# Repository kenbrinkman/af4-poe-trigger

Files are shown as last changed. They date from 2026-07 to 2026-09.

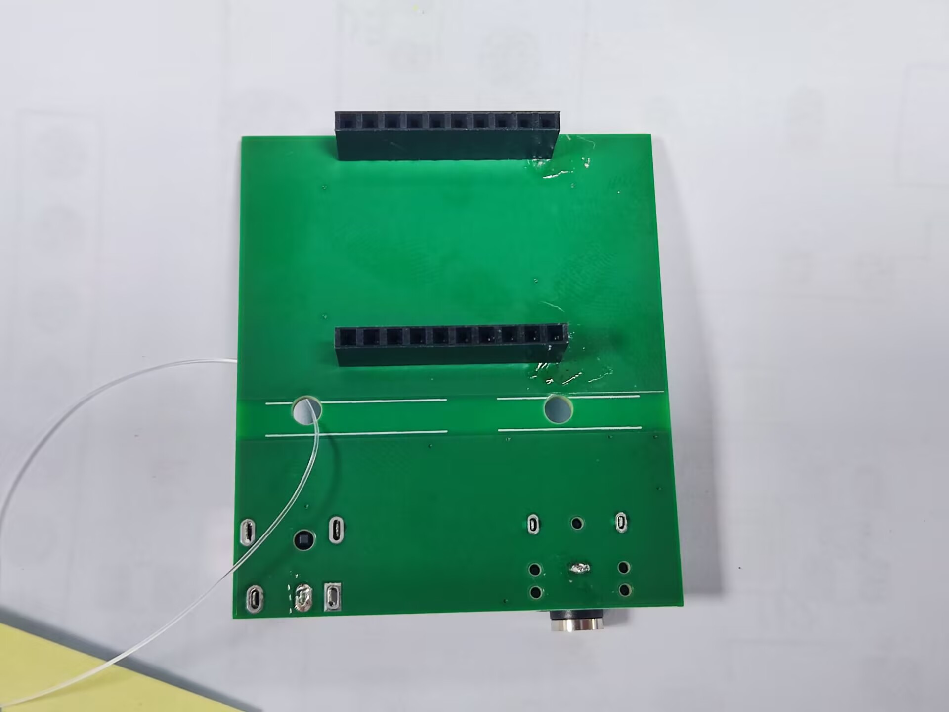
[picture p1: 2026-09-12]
pcb/BOARD REVIEW EQ/rework-2026-09-12-back.jpg

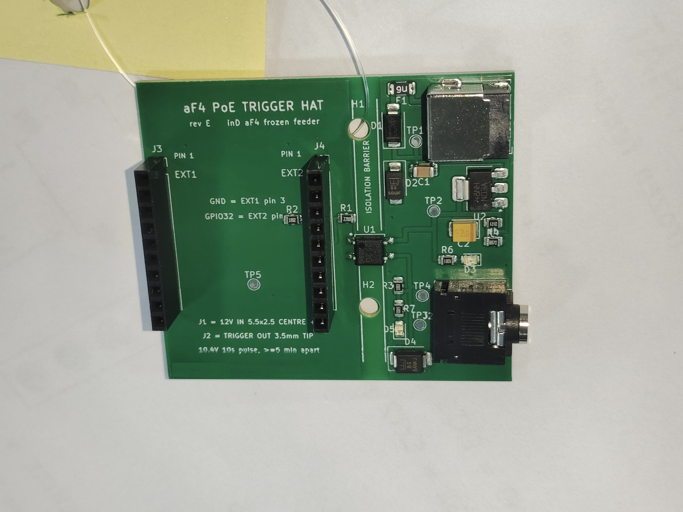
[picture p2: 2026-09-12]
pcb/BOARD REVIEW EQ/rejected-sample-2026-09-11-front.jpg

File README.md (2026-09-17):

# aF4 Frozen Feeder — ESP32 PoE Trigger

Replaces the inD connect WiFi dongle on the [inD aquatics aF4](https://www.indaquatics.com/products/af4) refrigerated frozen-food feeder with an Olimex ESP32-POE-ISO running ESPHome, triggering feeds via the aF4's 0-10V port and scheduled from Home Assistant.

## How it works

ESP32-POE-ISO → GPIO32 → 220Ω → AQY212GS PhotoMOS → switches the feeder's own 12V supply (regulated to ~10.4V by an on-board LM1117-ADJ) onto the 3.5mm trigger jack. Safety guardrails (20s pulse, 5-min lockout, restore-off, flash-persisted boot lockout) are baked into the ESPHome config on-device; HA is scheduler only.

**Rev E** puts all of that on a PCB "hat" that plugs onto the ESP32's EXT1/EXT2 headers and carries both panel connectors, assembled by PCBWay. The rev C hand-wired protoboard is retired.

> The trigger pin is **GPIO32**, not GPIO13. The Olimex board has a factory 2.2 kΩ pull-up on GPIO13 that can partially turn the PhotoMOS on during boot. See `docs/aF4-pcb-notes.md`.

## Where to start

| You are | Read |
|---|---|
| **A person, new to this project** | This file, then `STATUS.md` for where it stands, then `aF4-MASTER-REFERENCE.md` §1 and §2 |
| **An AI session** | `.claude/CLAUDE.md`, then `STATUS.md`. **Nothing else by default** — the routing table in `.claude/CLAUDE.md` §7 says where each answer lives |

Three documents are live. `STATUS.md` is the only one that describes current state; it is
rewritten, never appended to. `aF4-MASTER-REFERENCE.md` is the deep record — it carries a
section index and is meant to be grepped by `§N.N`, not read whole. `.claude/CLAUDE.md` holds
the durable facts and the routing table.

## Folder map

| Path | Contents |
|---|---|
| `STATUS.md` | **The only live-status doc.** Phase, what you may trust, open items |
| `aF4-MASTER-REFERENCE.md` | **The record.** Every load-bearing claim tagged with its provenance (measured / datasheet / calculated / asserted). Section-indexed |
| `.claude/CLAUDE.md` | Durable priming for AI sessions + the routing table |
| `.claude/settings.json` | Claude Code project settings and hooks — see `docs/git-rules.md` |
| `tools/` | `tools/section_index.py` — regenerates the master reference's section index |
| `docs/` | Subsystem references: feeder spec, PCB notes, BOM, assembly guide, enclosure notes, vendor-doc notes, meter test battery, and `docs/git-rules.md` |
| `firmware/` | `firmware/af4-feeder.yaml` — the ESPHome config as flashed, **source of truth**. `firmware/secrets.yaml` is gitignored |
| `hardware/enclosure/` | `hardware/enclosure/af4_enclosure_ocp.py` (parametric source, self-checking) and its STEP/STL exports; the printable rev E hat stand-in |
| `pcb/` | KiCad project, `pcb/gen_pcb.py` generator, the PCBWay upload package and the order record |
| `reference/diagrams/` | Wiring and system SVGs |
| `reference/vendor/` | Vendor CAD and PDFs — gitignored, not redistributed |
| `archive/` | 🚫 **Not authoritative and not in the read path.** Superseded handoff, the three dated reviews, rev C protoboard history. See `archive/README.md` |

## The board

`pcb/gen_pcb.py` is the source of truth: it generates `pcb/af4-trigger-hat.kicad_pcb`
deterministically from named coordinates, taken directly from the Olimex Rev N
KiCad source so the sockets line up by construction. Edit the script, not the
board file, then re-run it and `pcb/post.py` (fills the copper pours and runs DRC).

`pcb/af4-trigger-hat-rev-E-PCBWay.zip` is what you upload: Gerbers, drill, BOM,
centroid, fab notes.

## Vendor files (not in repo)

- ESP32-POE-ISO board CAD: [Olimex hardware files](https://github.com/OLIMEX/ESP32-POE-ISO)
- AQY212 PhotoMOS STEP: Panasonic
- aF4 / inD connect product docs: [inD aquatics](https://www.indaquatics.com/products/af4)

## Key trigger rules (inD 0-10V spec)

Feed triggers on ≥9V held ≥15s (inD publishes 6s/10s/15s across three guides — design to the longest); feeds ≥5 min apart; port must see ~0V for >60s to re-arm. Connecting the link port **overrides the aF4's internal 24h schedule** — an offline ESP32 means no feeding at all. Measured OEM dongle trigger voltage 10.37V open-circuit (don't feed raw 12V).

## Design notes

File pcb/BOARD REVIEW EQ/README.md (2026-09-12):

# BOARD REVIEW EQ — PCBWay assembly photographs, order YB1800644

Two sets, and telling them apart matters:

| File | What it is |
|---|---|
| `rejected-sample-2026-09-11-*.jpg` | **The REJECTED sample.** J3 and J4 standing on the top face, openings up. This is the defect described in §A3 |
| `rework-2026-09-12-*.jpg` | **The accepted reworked board.** Sockets on the bottom face, pin tails and solder on top. Verified in §A3.1. Downscaled from the email originals |

The reworked board still carries two accepted defects — excess solder and burnt flux on pin 10
of each socket row, and uncleaned flux on the bottom face at that end. Deliberate, not
overlooked: see §A3.1 and item 26.

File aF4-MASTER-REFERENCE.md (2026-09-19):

# aF4 PoE Trigger — Master Reference (rev E)

**Purpose of this document.** A single consolidated reference for the aF4 frozen-feeder
PoE trigger project, written to be *audited*. Every load-bearing claim carries a provenance
tag so a reviewer can tell what has been verified against a primary source and what is an
assertion that has not. The assertions are the interesting part — attack those first.

> 🔑 **Do not read this file whole** — it costs ~24,000 tokens. Use the section index
> below, then `grep -n "^### 2.4"` and read only that range.
>
> 🚫 **This file does not describe current state.** For phase, what may be trusted, and the
> open-items ledger, read **`STATUS.md`** — it is the only live-status document in this
> project. §8 below is the ledger of record for **item numbering**; `STATUS.md` is the
> ledger of record for **what is still open**.

Generated 2026-08-28, revised after independent audit the same day, after the 2026-09-01
bench and vendor-documentation passes, after the 2026-09-02 order went to fabrication, and
after the 2026-09-11 assembly-sample EQ found J3 and J4 built on the wrong face (§A3), after
the reworked board was verified and accepted 2026-09-12 (§A3.1), and after the order shipped
2026-09-14 (§A3.2). Canonical source for this file is the repo; the other project docs
(`docs/aF4-reference.md`, `docs/aF4-pcb-notes.md`, `docs/aF4-esp32-trigger-BOM.md`,
`docs/aF4-enclosure-notes.md`, `docs/aF4-assembly-guide.md`) remain authoritative in their own areas
and go deeper. This document does not replace them; it makes the whole thing checkable in
one pass.

## Provenance tags used throughout

| Tag | Meaning |
|---|---|
| `[MEAS]` | Kenny measured it on the physical hardware, date given |
| `[DS]` | Read off the manufacturer datasheet, verified 2026-08-28 |
| `[DIST]` | Manufacturer part number confirmed as a real, stocked part at a distributor, 2026-08-28 |
| `[CAD]` | Taken from vendor CAD source (Olimex ESP32-POE-ISO Rev N KiCad files) |
| `[SPEC]` | From inD aquatics' published 0-10 V setup guide |
| `[CALC]` | Derived. Inputs and working shown so the arithmetic can be rechecked |
| `[ASSERT]` | **Stated but not independently verified.** Treat as unproven |
| `[EQ]` | Found in a PCBWay engineering-query exchange, from photographs of the built boards |

---

<!-- SECTION-INDEX -->
## Section index

> 🔑 **Do not read this file whole.** Find the section here, then read only its
> line range. Numbers drift — confirm with `grep -n "^### 2.4" <file>`.

  - §A1 U1 is on the wrong footprint — the board cannot be built `[AUDIT]` — L126
  - §A1.1 FIXED — a project-local footprint built from Panasonic's drawing — L144
  - §A1.2 Rejected: `SO-4_4.4x4.3mm_P2.54mm`, matched on dimensions but not on pad shape — L167
  - §A1.3 Isolation, re-derived `[AUDIT]` — L196
  - §A2 `pcb/gen_pcb.py` says `SMAJ15A` for D2; everything else says `SMAJ13A` `[AUDIT]` — L218
  - §A3 J3/J4 are built on the wrong face — the fab data cannot carry a THT mounting side `[EQ]` — L229
  - §A3.1 Rework verified from photographs, and accepted with two defects open `[EQ] 2026-09-12` — L286
  - §A3.2 The EQ closed and the order shipped `[EQ] 2026-09-14` — L334
  - §A4 J1, the 12 V barrel jack, faces inboard on all five boards `[CAD] 2026-09-18` — L380
- **§1 What the system must do** — L576
  - §1.1 Requirements — L584
  - §1.2 Measured facts about the port — L595
  - §1.3 ⚠️ `[VENDOR] 2026-09-01` inD publishes THREE different hold times — L612
  - §1.4 ✅ `[VENDOR] 2026-09-01` RESOLVED — and the assumption was backwards — L652
- **§2 Circuit** — L681
  - §2.1 Regulator — the calculation that matters — L728
  - §2.2 Load on the 10.4 V rail — L761
  - §2.3 PhotoMOS drive — L812
  - §2.4 The GPIO13 problem — why the trigger is on GPIO32 — L837
  - §2.5 Protection — L879
  - §2.6 Indicator LEDs — L902
- **§3 Bill of materials — with verification status** — L936
  - §3.1 Sourcing traps recorded — L965
  - §3.2 Bought separately (not on the board) — L973
- **§4 Board** — L981
  - §4.1 Geometry from vendor CAD `[CAD]` — L999
  - §4.2 Verification status of the board — L1009
  - §4.3 Isolation — L1031
  - §4.4 The ordered board re-checked on KiCad 9.0.7 `[MEAS] 2026-09-17` — L1044
- **§5 Firmware** — L1079
  - §5.1 The safety architecture — L1085
  - §5.2 Timing check against the spec `[CALC]` — L1102
  - §5.3 ✅ `[AUDIT]` The lockout did not survive a reboot — CLOSED 2026-09-01 — L1122
  - §5.4 ✅ `[AUDIT]` The web server was a second, unauthenticated control path — CLOSED 2026-09-01 — L1146
  - §5.5 ✅ The related hygiene problem — the worse one — CLOSED 2026-09-02 — L1157
  - §5.6 `[AUDIT]` Held-high failure modes are bounded — the design's best safety property — L1175
  - §5.7 Home Assistant integration — L1186
- **§6 Enclosure** — L1267
  - §6.1 The vertical stack — the governing dimension — L1275
  - §6.2 Two details that are easy to lose — L1310
  - §6.3 The hat collided with an Olimex capacitor — raised 1.5 mm `[MEAS] 2026-09-16` — L1328
  - §6.4 Lid label turned to read portrait `2026-09-16` — L1441
- **§7 Errors already found and fixed** — L1461
  - §7.1 The inverse failure mode, named 2026-09-02 — L1496
- **§8 Open items** — L1516
  - §8.1 Commissioning gate (from `docs/aF4-assembly-guide.md` §6) — L1569
- **§9 Repository map** — L1600
  - §9.1 Toolchain constraints worth knowing — L1623
  - §9.2 The toolchain under Claude Code on the Mac `[MEAS] 2026-09-17` — L1638
- **§10 Audit status** — L1680
  - §10.1 Still unverified after the audit — L1696
  - §10.2 Bench work still unrun (`docs/aF4-meter-test-battery.md`) — L1730
- **§11 The PoE board was replaced `[MEAS] 2026-09-18`** — L1742
  - §11.1 Every board has two MACs, three apart, and the two systems use different ones — L1757
  - §11.2 Home Assistant migrates the device; it does not need a delete and re-add — L1776
  - §11.3 The OPNsense reservation is one line — L1798
  - §11.4 The OTA password rotation, and the character that broke it — L1810
  - §11.5 The standing corrections — L1835
- **§12 Commissioning passed, end to end `[MEAS] 2026-09-18`** — L1857
  - §12.1 Polarity, settled by meter — L1870
  - §12.2 The numbers — L1881
  - §12.3 The reef system is plumbed and running — L1918
  - §12.4 What a manual feed deliberately does not touch — L1937
  - §12.5 The decision taken, and the one question it opens — L1951
  - §12.6 The standing corrections — L1965
- **§13 The retired board was erased `[MEAS] 2026-09-19`** — L1981
  - §13.1 Erase, don't overwrite — and verify by read-back — L2004
  - §13.2 What survives, and what it means for reuse — L2020
  - §13.3 The standing corrections — L2041
- **§14 The case is closed, mounted, and the system is live `[MEAS] 2026-09-19`** — L2054
  - §14.1 The 23:45 "missed feed(s)" alert was correct, and cannot recur — L2084
  - §14.2 The standing corrections — L2102

<!-- /SECTION-INDEX -->

---

## A. Build blockers

### A1. U1 is on the wrong footprint — the board cannot be built `[AUDIT]`

`pcb/gen_pcb.py` places U1 on KiCad's `Package_SO:SO-4_4.4x2.3mm_P1.27mm`. That footprint's
own description points at an **OPTEK OPIA403** optocoupler: pads at x = ±3.15 mm,
y = ±0.635 mm — a **1.27 mm terminal pitch**.

The Panasonic AQY212GS is not that package. From Panasonic's own GU SOP4 datasheet
(`semi_eng_gu_sop4_1a.pdf`) `[DS]`:

| Parameter | AQY212GS (Panasonic) | Footprint in use |
|---|---|---|
| **Terminal pitch** | **2.54 mm** | **1.27 mm** ❌ |
| Body | 4.4 × 4.3 mm | 4.4 × 2.3 mm ❌ |
| Lead span, tip to tip | 6.8 ± 0.4 mm | 6.30 mm pad centres |
| Recommended pad | 0.5 × 1.0 mm on 2.54 mm pitch | 0.64 × 2.0 mm on 1.27 mm |

Every pin missed its pad by ~0.635 mm along the pin row.

### A1.1 FIXED — a project-local footprint built from Panasonic's drawing

**Final answer: `pcb/footprints/aF4.pretty/AQY212GS_SOP4_Panasonic.kicad_mod`**, authored from the
"Recommended mounting pad (TOP VIEW)" drawing in `semi_eng_gu_sop4_1a.pdf`:

| Panasonic recommended pad | Value |
|---|---|
| Pad size | **0.8 mm** across the pitch axis × **1.2 mm** along the lead axis |
| Pad centres, pitch axis | 2.54 mm |
| Pad centres, span axis | **6.0 mm** (±3.0) |
| Tolerance | ±0.1 mm |

Pads therefore span 2.40–3.60 mm from the part centre, against a lead tip at 3.2–3.6 mm
(6.8 ± 0.4 span). Toe lands on the pad across the whole tolerance range.

> **An interim fix got this wrong in an instructive way.** Before the drawing was readable,
> KiCad's `SO-4_4.4x4.3mm_P2.54mm` was used — it has the correct pad **centres** (±3.0,
> ±1.27) and an exact body match, but **its pads are rotated 90°**: 0.8 mm along the lead
> axis where Panasonic asks for 1.2 mm, and 1.2 mm across the pitch axis where Panasonic
> asks for 0.8 mm. The part would have mounted, but with no toe fillet at the far end of the
> lead-span tolerance. A footprint can match on pitch, body and pad centres and still be the
> wrong land pattern. **Read the drawing.**

### A1.2 Rejected: `SO-4_4.4x4.3mm_P2.54mm`, matched on dimensions but not on pad shape

`SOP-4_3.8x4.1mm_P2.54mm` was rejected: right pitch, but pad centres only 5.50 mm apart,
too narrow for a 6.8 mm lead span. The footprint now used matches Panasonic on every
dimension that exists in both:

| | Panasonic AQY212GS | `SO-4_4.4x4.3mm_P2.54mm` |
|---|---|---|
| Body | 4.4 × 4.3 mm | F.Fab outline 4.4 × 4.3 mm — exact |
| Terminal pitch | 2.54 mm | pads at y = ±1.27 — exact |
| Lead span | 6.8 ± 0.4 mm → tips at 3.2–3.6 | pads span 2.6–3.4 from centre |
| Pad 1 quadrant | — | unchanged, so the netmap needed no edit |

**Regenerated in full:** `pcb/gen_pcb.py` → `pcb/post.py` → Gerber/drill export → `pcb/make_package.py`.
Three routing waypoints that had been hard-coded to the old pad rows now derive from the
pad positions. The "ISOLATION BARRIER" silk text moved from y 128.00 to 125.50, because the
taller footprint pushed U1's reference designator onto it.

**Verification:** DRC returns **61 items, identical in class and count to the pre-fix
board** — 0 clearance, 0 courtyard, 0 hole, 0 copper-to-edge, 0 unconnected, 0 mask
bridges; the remainder are the same silkscreen and library-footprint cosmetics as before.
Drill tools 0.450 / 0.700 / 0.800 / 1.000 / 1.200 / 2.130 / 3.200 mm, no plated slot under
0.70 mm. BOM ≡ PARTS ≡ board refs (21). Centroid 17 SMD. The board was also **rendered and
looked at**, not merely measured.

`pcb/gen_pcb.py`'s `load()` now checks a project-local `footprints/` directory before the stock
KiCad libraries, so `aF4.pretty` holds any part whose stock footprint is wrong for the part
actually being bought.

### A1.3 Isolation, re-derived `[AUDIT]`

The **"4.3 mm pad-to-pad across U1"** figure is **withdrawn** — it was the copper gap of the
OPIA403 pattern, not of the AQY212GS. The real numbers, measured off the regenerated board:

| | Value |
|---|---|
| U1 pad-to-pad copper gap | **4.80 mm** (was 4.30 on the wrong footprint) |
| Copper-free band, by design | 4.70 mm, x 121.65–126.35 |
| **True minimum logic-to-power creepage** | **4.425 mm** (was **4.225 mm** before the fix) |

The governing constraint is **not U1** — it is **R1 pad 2**, whose logic-side copper reaches
x 121.925 and intrudes 0.275 mm into the nominal band, against the GNDP pour edge at
126.350. That was true of the old board too; the footprint fix improved the real creepage by
0.2 mm. Both mounting holes inside the band are **NPTH — no copper**. Zone fills stop
exactly on the band edges. At 4.4 mm between two SELV domains, creepage is nowhere near the
weak link in the 1500 Vrms argument.

*How it got past DRC: the same mechanism as the slot widths — DRC checks pads against
tracks, not pads against the physical part. The footprint was well-formed and wrong,
which is this project's signature failure mode (§7).*

### A2. `pcb/gen_pcb.py` says `SMAJ15A` for D2; everything else says `SMAJ13A` `[AUDIT]`

The BOM, `pcb/make_package.py` and all prose specify SMAJ13A. Turn-key sources from the BOM,
so the boards would have received the 13 V part — but the "source of truth" script
contradicted the BOM. **Fixed 2026-08-28:** the script now says SMAJ13A. If a 15 V
standoff was ever the intent it was never propagated anywhere, and adopting it
deliberately would close the open-circuit-voltage question in §2.5 by fiat
(SMAJ15A breakdown 16.7–18.5 V still clamps far under the AQY212's 60 V rating).

---

### A3. J3/J4 are built on the wrong face — the fab data cannot carry a THT mounting side `[EQ]`

**Found 2026-09-11 from PCBWay's assembly sample photographs.** Both 1 × 10 sockets are
fitted on the **top** face with their openings pointing up. They belong on the **bottom**
face: plastic body hanging below the board, solder joints on the top side.

**This is our error, not PCBWay's.** They built exactly what the data said.

Three project documents already fix the socket below the board, and they agree:

| Source | What it says |
|---|---|
| §6.1 stack | `z = 4.12` top of the male header plastic, `z = 12.62` hat underside. The gap is **8.50 mm — the socket body height exactly.** With the socket on top, the hat underside would sit at 4.12 and every line below it moves |
| `docs/aF4-pcb-notes.md` | "male header plastic 2.54 mm + socket body 8.5 mm ⇒ the hat's underside sits ~11.0 mm above the ESP32's top face" |
| `docs/aF4-assembly-guide.md` §3, §5 | Male headers "pins pointing up" on the ESP32, then "**Hat down onto the two headers**". Openings must face down |
| `hardware/enclosure/af4_hat_dummy_ocp.py` | The printed fitment dummy is the fourth witness and the most literal one. The plate is `box(..., HAT_Z, ..., HAT_TOP)` = 12.618→14.218. J1, J2, U1 and the LED bumps are all fused **above** `HAT_TOP`. The two socket bars are `box(bx0, BAR_Y0, HAT_Z - SOCKET_H, bx1, BAR_Y1, HAT_Z)` = **4.118→12.618, entirely below the plate**, and peg into holes cut in its underside. Its own comment: "The bar underside is the top of the male header plastic the sockets will sit on (z = 4.118)" |

As built the Olimex pins reach ~8.5 mm above the ESP32's top face while the hat underside
sits at 12.62 mm. **They never touch** — and a socket cannot be entered from below in any case.

**Why nothing caught it.** The mounting side of a through-hole part is invisible in every
machine-readable file in the package:

1. `pcb/gen_pcb.py` places J3/J4 with the same `place(...)` call as everything else, so the
   footprints sit on `F.Cu` with silkscreen on `F.SilkS`. Nothing says "fit from the reverse".
2. `pcb/af4-trigger-hat-centroid.csv` carries **SMD rows only** — no J1, J2, J3 or J4, and no
   side column. The side was never in machine-readable data at all.
3. `pcb/PCBWay-README.txt` ASSEMBLY reads "**Sides populated: top only**". Critical note 5
   already said J3/J4 "must be seated flush and square — they mate with a header on another
   board" and stopped one sentence short of naming the face.

Gerbers encode copper, mask and silk. **They do not encode which side a leaded part is
inserted from.** For an SMD part the side is implied by the layer; for a THT part it is not
implied by anything, because the holes are identical either way.

**The rework is cheap and must be described that way to PCBWay:** same holes, same parts,
plated through with pads on both faces, so **no PCB change and no BOM change**. Pin 1 stays
in the hole it is in now — a 1 × 10 in-line connector does not mirror when flipped. The top
silkscreen legend ends up on the opposite face from the part, which is cosmetic.

> **Generalised lesson, and it is the §7 pattern in a new costume:** a fact that lives only
> in prose is a fact the factory cannot act on. **Any part fitted from the non-standard face
> must be named by designator in the fab note *and* have its footprint on that face in the
> CAD.** Do not rely on an assembly drawing, and put the THT parts in the centroid with a
> side column so the machine-readable package carries it too.

Reply text and the full photo-by-photo check: `pcb/pcbway-EQ-2026-09-11-reply.md`.

**Everything else in the sample photos was verified correct** against the BOM and the
pad-level geometry in `pcb/af4-trigger-hat.kicad_pcb`: U1 pin 1 top-left, U2 tab left,
D1 band bottom and D2 band top, C2 positive stripe right, all seven resistor codes,
J1 5 soldered slots + 1 NPTH post, J2 3 soldered slots + 5 NPTH pegs, all 21 designators
populated. **D3/D5 LED polarity is not resolvable at the photo's resolution** and was
referred back to PCBWay to confirm against the centroid.

---

### A3.1 Rework verified from photographs, and accepted with two defects open `[EQ] 2026-09-12`

PCBWay reworked one board and photographed both faces. **The A3 defect is fixed.**

⚠️ **The two photographs originally saved into `pcb/BOARD REVIEW EQ/` as `Front.jpg` and
`Back.jpg` are the REJECTED sample, not the reworked board.** They were saved on the evening of
2026-09-11, after the reply had already gone out, and the front one plainly shows both sockets
standing on the top face. **Renamed 2026-09-12** to `rejected-sample-2026-09-11-*.jpg`, with the
reworked pair alongside as `rework-2026-09-12-*.jpg` and a `README.md` in that folder saying
which is which. *Do not read the folder name as "the current board".*

**What the rework photographs show — verified 2026-09-12:**

| Check | Result |
|---|---|
| J3/J4 mounting face | ✅ Bodies on the **bottom** face, openings down, pin tails and solder on the **top** face — as §6.1 requires |
| Pin 1 | ✅ Still in the square pad on both. Not mirrored, not renumbered |
| Seating | ✅ Both flush against the board, square, parallel to each other and to the edges. **The J3 body appearing to overhang the board edge in the bottom-face photo is perspective** — the 8.50 mm body seen at an oblique angle — not lateral offset |
| Collateral damage | ✅ R1 and R2 sit within a few mm of J4 and are intact |
| Isolation band | ✅ Clean. No solder balls, and the bottom-face flux residue stops short of the upper silk line |
| J4's ten joints | ✅ Silver annulus with the gold pin end visible in each. Properly wetted |
| J3's ten joints | ⚠️ **Not gradeable.** That row is shot at too oblique an angle; the barrels read as open with the pin off-centre, which is as likely to be the camera angle as a defect |

**The two defects accepted, both carried over unfixed from the 2026-09-11 reply:**

1. **Pin 10 of each row** — the far end from the PIN 1 marker — is a dull grey irregular blob
   with burnt flux spatter and soldermask staining spreading from it. Rework heat made it
   worse. This is the same joint the earlier reply asked to be reflowed.
2. **Flux residue on the bottom face** at that same end of both sockets: heavy clear smears
   with white crystallised streaks, uncleaned.

**The decision, Kenny 2026-09-12: accept and ship, do not ask for a second rework.** The
reasoning is worth keeping because it generalises. **Five boards are being built and one
working board is needed.** Both defects are local to two joints, both are repairable at the
bench with an iron and IPA, neither propagates, and neither can worsen in transit. A second
rework round would restart the build clock — see §7's standing note on EQ cost — for cosmetic
gain on parts that will be inspected and touched up locally anyway. **Vendor goodwill spent on
a defect you can fix yourself in five minutes is goodwill you do not have for a defect you
cannot.**

Consequence for the build: **inspect all five on arrival and select the best board**, rather
than assuming board 1 is the one to fit. Reflow the two pin-10 joints and clean the flux
before the item-12 header work. Tracked as item 26.

Reply text and the accept/reject reasoning: `pcb/pcbway-EQ-2026-09-12-rework-accepted.md`.

---

### A3.2 The EQ closed and the order shipped `[EQ] 2026-09-14`

PCBWay order `YB1800644` reads **"This order was Shipped (Awaiting delivery)"** as of
2026-09-14, with the Logistics Information table giving **DHL (DTP)**, shipping time
**2026-09-14**, and the tracking-number column **blank**. That ends the A3 thread: the
acceptance reply released the rework, the remaining four boards were built, and all five left
the factory. Nothing is owed to PCBWay and nothing on this project waits on them.

**Shipped 12 days after the order was placed**, against a quoted 26–28 day lead time — and that
is *with* two engineer questions, each of which restarts the build clock (§7). The J3/J4 rework
round cost nothing against the quote. **Treat PCBWay's quoted lead time as a ceiling, not an
estimate**, and do not plan the next run's schedule around it.

⚠️ **The "Estimated Finish Time" reminder on the order page is not maintained.** It still read
`2026-09-29` on the day the boards shipped — it is the pre-EQ fabrication estimate and was never
recalculated, not by the 09-02 EQ, not by the 09-11 one, and not by the shipment. **The status
line and the Logistics Information table are the live fields; the reminder line is decoration.**
This is what item 21 was written to chase, and the answer is that there is nothing there to read.
**No delivery date is published anywhere on the order page.** DHL Express out of China typically
runs 3–6 business days to the US east coast, which puts arrival loosely in the 09-18 to 09-23
window — a working band, not a commitment, and not to be quoted as one.

**The blank tracking number is normal** within a day or two either side of a status flip.
Kenny's call on 2026-09-14 was **not to chase the waybill** and to let it appear. If it has not
by roughly 09-18, the order page is still the place to look before mailing anyone: PCBWay's
email is not a reliable signal for order events, which is why the page is the source of truth.

**DHL (DTP)** is understood to be PCBWay's duties-and-taxes-prepaid service, i.e. the $56.99 of
shipping, tax and handling taken at checkout should cover import charges and nothing should be
collected at the door. ⚠️ **Not verified against PCBWay's own published terms.** If DHL presents
a duty invoice on delivery, check it against the order before paying it rather than assuming it
is owed.

**What this changes for the build:**

- **Item 21 closes**, overtaken by events rather than answered (see above).
- **Item 26 stops being a note and becomes the next action.** The arrival inspection is now the
  top of the open-item list, ahead of items 12 and 16, all three in one bench session.
- ⚠️ **Only board 1 has ever been seen.** The other four were built after the 09-12 acceptance
  and were never photographed. They are *expected* to carry J3/J4 on the bottom face because the
  reworked sample was accepted as the pattern, but that is an inference, not an observation.
  **Check the mounting face on every board before selecting one** — the same defect that A3
  caught is exactly the one that a second build run can reproduce silently.

---

### A4. J1, the 12 V barrel jack, faces inboard on all five boards `[CAD] 2026-09-18`

The boards arrived 2026-09-18. Kenny saw it immediately: nothing can be plugged into the
12 V input. **J1 is rotated 180° from usable, on every board, and the error is in our fab
data — not in PCBWay's build.** Same family as A3: ours, not theirs. No complaint, no credit
request, no email.

**The proof, from two independent sources.** `pcb/gen_pcb.py` places J1 at rotation **270**
(`"J1", "PJ-079BH", 144.00, 121.00, 270`), which `pcb/af4-trigger-hat.kicad_pcb` carries as
`(at 144 121 -90)`. CUI's own STEP model for `BarrelJack_CUI_PJ-079BH_Horizontal` puts the
Ø5.5 receptacle bore at footprint-local **y +10.32** and the 2.5 mm centre pin on the same
axis. At rot 270 that bore maps to board **x = 133.68** — pointing at the middle of the hat.
The jack's blank back face lands at x 145.28, 0.87 mm inside the board's right edge at 146.15.

**J2 is correct, and for the same reason J1 is not.** The SJ1-3523N's bore is also at
footprint-local +y, but J2 is placed at rot **90**, which maps its nose to x 148.45 — 2.30 mm
proud of the board edge, as intended. **The two connectors needed the same handedness and were
given opposite rotations.** One number, 180° apart.

**The part cannot be re-seated.** J1's three pins sit at footprint-local x = 0, −3.2, −8.5:
gaps of 3.2 and 5.3 mm. No in-plane rotation and no bottom-side fit maps that set onto itself —
the gaps come back in the wrong order. The two shield tabs and the Ø2.13 locating boss settle
it. A PJ-079BH can go into those holes exactly one way, and that way is backwards.

**Everything else about the board is unaffected.** The pads are correctly netted — pad 1
`+12V_RAW` at (144.00, 121.00), pad 2 `GNDP` at (144.00, 112.50), pad 3 the jack's internal
switch contact, unconnected. Nothing is damaged, no other net is touched, and no other
component is placed inside J1's 11.5 × 10.1 mm body shadow.

#### The second error, in the enclosure, on the same part

`hardware/enclosure/af4_enclosure_ocp.py` carried `J1_Y = -116.56` under the comment *"jack
axes, from the vendor 3D models"*. **−116.56 is the jack's BODY centre** (footprint-local
x −4.45). The bore axis is at local x −3.19, i.e. **y −117.81**. The wall hole was therefore
**1.25 mm off axis**, against 0.95 mm of radial slack in a Ø7.4 hole for a Ø5.5 plug. **The
plug would have fouled the wall even if the jack had faced outward.** A second datum taken by
hand instead of from the part — §6.3's lesson, repeated on the very next component.

#### Why nothing caught it

Three checks looked as though they covered this. **All three were hollow**, and each one was
hollow in a different way:

| Check | Where | Why it could not fail |
|---|---|---|
| `J1 plug engagement` | `af4_enclosure_ocp.py` | Arithmetic on `J1_FACE_X = 145.28` — a hand-typed constant for the *wrong face*. It measured the assumption against itself |
| `J1 bore reaches past the wall inner face` | `af4_hat_dummy_ocp.py` | Evaluated `J1_X1 - (J1_X1 - J1_BORE_L) >= J1_BORE_L`, i.e. `9.5 >= 9.5`. Algebraically true for every input |
| `5.5 mm plug path clears the case wall bore` | `af4_hat_dummy_ocp.py` | Intersected the plug with the **case** only, never with the jack body. It tested the hole, not the jack |

The fitment dummy was built to prove the enclosure before the boards came back, and it did its
job on everything it actually tested. But it took J1's bore face from the same hand assumption
the enclosure did, so it agreed — and agreement between two models fed the same wrong number is
not verification. **§9 already says a script can only ever agree with itself; this is what that
costs when the number it agrees about is wrong.** `verify_enclosure.py`, which exists precisely
to break that circle, reads the STL and the parameters — and the parameters were the error.

→ New lesson, and it is the sharper form of §6.3's: **a check whose result is fixed by its own
inputs is not a check.** Before trusting one, ask what value of the world would make it fail.
If there is none, it is a comment.

#### The decision: use all five boards as built

Taken by Kenny, 2026-09-18, and it is better than the alternative of desoldering J1.

- **J1 stays fitted and dead** on every board. Its bore opens inboard at x 133.68, where D1 and
  C1 block it, so nothing can ever be plugged into it by mistake. Its contacts stay on
  `+12V_RAW` / `GNDP` — inert inside a closed case.
- **The 12 V feed is taken from J1's own pad tails on the hat's UNDERSIDE**, which is open air:
  board x 144 is 26 mm outboard of the ESP32's right edge (118.15), a fact `af4_enclosure_ocp.py`
  already asserts. Clear height from the floor at z −9.50 to the hat underside at 14.118, minus
  J1's 3.4 mm pin drop.
- **From there to a panel-mount jack in the +X wall**, at enclosure **y −172.50, z +6.00** —
  mid-window between the hat's near edge (−160.0) and the −Y/+X lid boss (edge −184.5), and low
  enough that the cable passes under the hat.
- **The old J1 wall penetration is gone**, Ø7.4 hole and Ø13 × 1.8 counterbore both. The wall is
  solid there, and `verify_enclosure.py` check 4 now proves it on the printed mesh.
- **A polarised 2-pin inline connector goes in the run**, near the jack. Without one the hat is
  tethered to the case and cannot be lifted off its headers for service.
- **A cable tie post** stands on the floor at (143.00, −162.50), between the jack and the hat.
  The wires land on J1's pad tails, which is the weakest joint in the repair; nothing should be
  able to pull on them.

**Identifying the two pads from the underside.** The three tails are in a row at board x 144,
and the asymmetric spacing is the key: **the wider gap is on the ground side.**

| Order, running toward J2 | Net | Board y | Gap to the next |
|---|---|---|---|
| nearest the board's own edge | `GNDP` — pad 2 | 112.50 | 5.3 mm |
| middle | the jack's switch contact — **unconnected, leave it** | 117.80 | 3.2 mm |
| nearest J2 | `+12V_RAW` — pad 1 | 121.00 | — |

Confirm with a meter before soldering: **the GND tail to TP4 is a dead short.** That pins it
unambiguously. ⚠️ **Do not try to confirm +12 V against TP1 the same way** — F1 and D1 sit
between them, so it reads a diode drop, not continuity, and a correct board looks like a fault.

#### The part: DALQUIS DC-099, already in stock `[MEAS] 2026-09-18`

Not ordered — **found in the parts drawer.** Kenny already had six, bought 2026-07-18, and
**rev C used this same part** before the hat existed (`docs/aF4-pcb-notes.md`; the rev C
enclosure had a "DC-099 hole in the input wall" that rev D deleted). 5.5 × 2.5 mm, 10 A,
threaded panel mount, **150 mm of 18 AWG pre-soldered leads — red is +12 V, black is −**,
recorded on both rev C protoboard diagrams in `archive/`. No soldering at the panel at all,
which makes it strictly better than the Same Sky PJ-005B that was the fallback.

| | | Provenance |
|---|---|---|
| Barrel, full Ø | 11.50 mm | `[MEAS]` |
| **Barrel flat**, face to opposite arc | 10.50 mm | `[MEAS]` |
| Flange thickness | 1.50 mm | `[MEAS]` |
| Nut: thickness / across flats / across corners | 3.00 / 14.00 / 15.80 mm | `[MEAS]` |
| Thread length | 9.00 mm | `[VENDOR DRAWING]` |
| Overall length | 20.00 mm | `[VENDOR DRAWING]` |
| Flange Ø, body Ø | 16.00, 13.00 mm | ⚠️ `[ASSUMED UPPER BOUND]` |

**The vendor drawing was ambiguous and the caliper resolved it.** It gives "2 mm", "9 mm",
"9 mm" and an overall "20 mm" with no indication of which are axial and which are diameters.
Two readings were coherent: 2 + 9 + 9 = 20 as consecutive axial segments, or a 2 mm flange
with 9 mm thread and body *diameters*. **A measured 11.5 mm barrel rules out the second**, so
the thread is 9 mm long — which clears the 3.0 mm wall and its 3.0 mm nut with 3.0 mm to spare.
Flange and body diameters remain uncalipered and are carried as upper bounds; both only feed
the clearance envelope, which the nut's 15.80 mm across-corners dominates anyway, and **anything
up to Ø20 still passes every check.**

#### Retention: the barrel has a flat

⚠️ **This replaced a worse design.** The script carried an opt-in pad-plus-captive-hex-pocket
scheme, written when the part was unknown, to stop the jack turning when a plug is pushed in.
**The DC-099's barrel carries a flat, so the part keys itself** — better than anything that
could have been printed around it, and it costs nothing.

The wall hole is therefore a **D, flat UP**: Ø11.90 bored, then the wall put back above a plane
4.95 mm over the axis, leaving a 1.00 mm key. Flat up also makes the hole's roof a flat bridge
instead of a curved overhang, so **unlike J2 this hole needs no teardrop crown**, and its whole
envelope stays inside Ø11.90 where any plausible flange covers it. The stack is simply flange
outside, 3.0 mm wall, nut inside.

The pad and hex-pocket code is gone, along with the now-unused `hex_x` helper. It was the right
design for an unknown part and the wrong one for this part; a hex pocket would have eaten the
wall the flange clamps.

**Fit the jack before the boards go in.** The nut is 14 mm across flats and wants a spanner or
fingers inside an otherwise empty box.

#### The wiring, as executed `2026-09-18`

Kenny soldered the DC-099's leads to J1's pad tails on the hat's underside the same day:
**red to pin 1 (`+12V_RAW`), black to pin 2 (`GNDP`), pin 3 left bare.** Re-soldered once so
the leads exit **inboard** rather than across the board's right-hand edge — see the routing
constraint below.

**The pad identification is corroborated by Same Sky's own PCB layout drawing**, which is worth
recording because it is an independent source from the footprint: the drawing gives **5.30 and
3.20** down the pin column and **6.20 and 3.60** down the shield-tab column, and our footprint
has exactly those gaps. Two consequences:

- **Pin 1 sits in the tight pair with pin 3; pin 2 is the far one.** The wide gap is the ground
  side, in both columns, on the low-y side of the board.
- The tab column gives a **second, independent read** of which way round the part is, using
  features that carry no wires. If the pin row is ever ambiguous under solder, read the tabs.

⚠️ **Polarity is not confirmed until the meter says so.** The photograph agrees and the drawing
agrees, but the deciding test is **black tail → TP4 reads a dead short**. Do not attempt the
mirror test on red against TP1: F1 and D1 sit between them, so a *correct* board reads a diode
drop and looks like a fault. A reversal is not destructive — D1 is a series Schottky and blocks
it — so the failure mode is D3 staying dark at commissioning 6.1, not damage.

#### Routing: the 0.50 mm you cannot see

🚫 **The 12 V leads must never cross the hat's right-hand edge.** `HAT_X1` is 146.15 and `IX1`
is 146.65: **0.50 mm**, and the enclosure script asserts exactly that gap. A wire laid over that
edge is crushed when the lid goes on, and the damage is invisible from outside.

Take the leads straight **down** off the pad tails into the void beneath the hat, then along the
floor to the tie post and the jack. There is room: the pads sit at board x 144, **26 mm outboard
of the ESP32's right edge**, so nothing is under them but ~20 mm of air between J1's 3.4 mm pin
drop and the case floor at z −9.50.

#### The lid does not change

✅ Verified rather than assumed, 2026-09-18: `aF4-trigger-lid.stl` is **byte-for-byte identical**
to its state at commit `29f1682`, which is what the 2026-09-17 lid was printed from — unchanged
since `5cb4b7b`, the portrait-label commit. Every change in this section is +X wall and floor
geometry. The case's external envelope is unchanged at 65.2 × 117.0 × 39.9 mm, so the existing
lid still mates. **Print the case only.**

#### Carried to rev F

- **J1 to rotation 90**, with the body re-placed so the nose overhangs the right edge. This is a
  re-layout of that corner, not a nudge: at rot 90 the pin column moves to x ≈ 135.8.
- **Both jack datums taken from the vendor STEP**, bore axis and bore face, never from a body
  outline or a typed face coordinate.
- Already carried, unchanged: J3/J4 footprints onto `B.Cu` (item 24), the hat underside kept
  clear over the Olimex cap, C1's EOL replacement, R5 to 0.25 W (item 18), J1/J2 sourcing.

---

## 1. What the system must do

Replace the inD connect WiFi dongle on an inD aquatics aF4 refrigerated frozen-food feeder
with an Olimex ESP32-POE-ISO running ESPHome, so feeds can be scheduled from Home Assistant.

The aF4 exposes a 3.5 mm "0-10 V" trigger port. It is a **threshold input, not an analog
level** — no DAC is required.

### 1.1 Requirements

| # | Requirement | Value | Source |
|---|---|---|---|
| R1 | Trigger threshold | ≥ 9 V held **≥ 15 s** | `[VENDOR] 2026-09-01` — see note |
| R2 | Re-arm | port must see ~0 V for > 60 s | `[SPEC]` — verbatim from inD's Neptune Systems page, audit-verified 2026-08-28 |
| R3 | Minimum feed spacing | ≥ 5 minutes | `[VENDOR] 2026-09-01` — Apex guide states it |
| R4 | Do not drive the port with raw 12 V | OEM dongle measured at **10.37 V** | `[MEAS] 2026-07-10` |
| R5 | Feeder must stay powered continuously | it is a refrigerator | `[SPEC]` |
| R6 | Supply | 12 V, 12.5 A external brick, barrel **5.5 × 2.5 mm centre-positive** | `[MEAS] 2026-07-10` |

### 1.2 Measured facts about the port

| Measurement | Result | Source |
|---|---|---|
| Tip↔sleeve at rest | 0 V | `[MEAS] 2026-07-10` |
| Tip↔sleeve during an OEM-triggered feed | 10.37 V | `[MEAS] 2026-07-10` |
| "Link" icon mechanism | **mechanical** — a bare plug with nothing attached lights it. Jack insertion switch, no electrical sensing | `[MEAS] 2026-07-10` |
| Consequence | no bleed resistor needed for link detect; rest voltage is genuinely 0 V | `[CALC]` |
| Tip↔sleeve resistance, unpowered | **~11 kΩ** → **~0.95 mA at 10.4 V** | `[MEAS] 2026-09-01` |
| OEM plug wiring | **TRS plug, only tip + sleeve wired. Ring floats** | `[MEAS] 2026-09-01` |
| OEM dongle output, open-circuit | 10.35 V settling to **10.37 V** — confirms R4 was an *open-circuit* figure | `[MEAS] 2026-09-01` |
| OEM dongle turn-on overshoot | **16.40 V**, brief, unloaded — boost startup overshoot | `[MEAS] 2026-09-01` |
| OEM dongle pulse behaviour | **pass-through, no fixed-width pulse** — holds until toggled off | `[MEAS] 2026-09-01` |
| 12 V brick, open-circuit | **12.13 V**, stable, centre-positive | `[MEAS] 2026-09-01` |
| 12 V rail loaded (TEC + feed) | idle **11.84–11.86 V**, minimum **11.77 V** across 3 feed cycles | `[MEAS] 2026-09-01` |
| aF4 unit under test | PN **10102101**, SN **130063** — outside every documented serial range | `[MEAS] 2026-09-01` |

### 1.3 ⚠️ `[VENDOR] 2026-09-01` inD publishes THREE different hold times

R1 previously read **`≥ 9 V held > 6 s`**. That figure is genuine: the 2026-08-28 audit
fetched inD's **Neptune Systems page** and quoted it verbatim — *"9v or higher signal for
greater than 6 seconds"*. R1–R3 were all verified against that page. **The 6 s was not
invented.**

The problem is that inD's own guides **disagree with each other**:

| inD source | Hold time |
|---|---|
| Neptune Systems 0-10 V page (fetched 2026-08-28) | **> 6 s** |
| inD Connect dongle guide (read 2026-09-01) | **≥ 10 s** |
| Coralvue Hydros guide (read 2026-09-01), `Run Time 00:00:15` | **≥ 15 s** |

The current Neptune **Apex** article no longer states a hold time at all, so the help
centre appears to have been reorganised since August.

**Design to the longest published figure.** R1 is therefore set to **≥ 15 s**. The old 10 s
firmware pulse satisfied the 6 s figure but **failed the 15 s one**, so the timing check's
"67 % margin" was margin against only the most permissive of three numbers.
✅ **Fixed in the repo 2026-09-01: 20 s pulse, tail left at 290 s** — a 310 s cycle, which
clears all three hold times *and* closes the separate zero-margin-at-300 s audit item. The
280 s tail first sketched here would have kept the cycle at exactly 300 s; keeping the
290 s was free. **Still needs flashing** — open item 11.

`[MEAS] 2026-09-01` closes the obvious escape route: the OEM dongle **passes the toggle
through** rather than emitting a fixed-width pulse, so inD's "10 seconds" describes the
**port**, not dongle logic.

**Key design insight:** R1 defines a *window*, not a setpoint. 10.37 V is merely what the
OEM dongle happens to produce. This is why a fixed resistor divider is the right answer and
a trimpot is not.

⚠️ `[AUDIT]` **The upper end of that window is an inference, not a spec.** inD's guide
states a 9 V floor and **no maximum voltage**; the "below 12 V" ceiling is this project's
own reading of the 10.37 V OEM measurement. The worst-case output of 10.88 V (§2.1) already
exceeds what the OEM dongle produces by half a volt. Almost certainly fine for a threshold
input — but that ceiling should carry an `[ASSERT]` tag, and until now it read as `[SPEC]`.

### 1.4 ✅ `[VENDOR] 2026-09-01` RESOLVED — and the assumption was backwards

This document previously asked whether the internal 24 h timer keeps running under
external triggering, and **assumed yes**. Both inD's Neptune Apex and Coralvue Hydros
guides state the built-in schedule is **completely overridden when the link port is
connected** — Hydros words it as *connection*, not signalling.

**So once J2's cable is plugged in the aF4 never feeds on its own.** An offline ESP32,
a mid-OTA reboot, or `input_boolean.reef_af4_schedule_enabled` left OFF means the fish
are **silently not fed**.

Every guardrail in this design prevents an *extra* feed. This is the opposite direction.

⚠️ **Corrected 2026-09-05.** This paragraph previously read "has **no detection at all**"
and proposed alerting when `counter.reef_af4_feeds_today` is still 0 past the scheduled
time, citing "open item 12". Both were wrong, and the wrongness is the point: **that alert
already existed** when this was written — `automation.reef_tank_feeder_health_watchdog` has
run a 23:45 counter-vs-elapsed-feed-times backstop and a board-offline branch since
2026-08-27 (§5.7). It was opened as **item 17** — not item 12, which is the headers — and
**withdrawn the same day**. See §7.1.

**What is actually detected:** an offline board (watchdog, 15 min), a missed scheduled feed
(watchdog, 23:45), and a skipped or unacknowledged press (the scheduled-feed automation).
**What is not:** whether food physically came out — §8 item 20, the one real remaining gap.
An over-temperature fault stops the feeder, never self-clears, and is invisible to every
mechanism above.

---

## 2. Circuit

```
 feeder 12 V brick
   │
   └─ barrel Y-splitter ──→ J1 (PJ-079BH, 5.5 × 2.5)
                             │
                             └─ F1 PPTC 0.10 A hold ──→ +12V_F
                                                          │
                                     D1 SS14 (reverse polarity, in series)
                                                          │
                            ┌───────────────┬─────────────┴──→ +12V
                            │               │
                     D2 SMAJ13A        C1 10 µF          U2 LM1117MPX-ADJ
                       (clamp)          ceramic          R4 121 Ω  OUT→ADJ
                            │               │            R5 887 Ω  ADJ→GND
                           GND             GND                    │
                                                                  │
   +10V4 rail ────┬──────────────┬─────────────────────────────────┘
                  │              │
            C2 10 µF        R6 1.0 k
            tantalum         D3 green      U1 AQY212GS PhotoMOS (pins 3/4)
                                                          │
   TIP ───┬───────────────┬──────────────┬────────────────┘
          │               │              │
     R3 100 k        R7 6.8 k        D4 SMBJ13CA      J2 (SJ1-3523N) tip
      bleed           D5 yellow       (bidir)
          │
         GND

 ESP32-POE-ISO ── GPIO32 ─┬─ R1 220 Ω ── U1 LED anode  (pin 1)
                          │
                          └─ R2 10 k ── GND
                             U1 LED cathode (pin 2) ── logic GND
```

The PhotoMOS is the **only** thing crossing between the logic domain and the feeder-power
domain. Separate ground pours, no copper bridging.

> `[AUDIT]` The chain is **series**: J1 → F1 → D1 → then D2, C1 and the LDO all
> *downstream* of the Schottky. An earlier draft of this diagram showed D2 clamping
> `+12V_RAW` upstream of D1, which is not what `pcb/gen_pcb.py` builds. The built topology is
> the better one — D2 never sees a reverse input, and F1 still protects a shorted D2 —
> but the diagram was wrong, and an auditor working from it would have signed off on a
> circuit that was never built. The pad-to-pad figure that used to appear here is
> withdrawn; see §A1.

### 2.1 Regulator — the calculation that matters

`[DS]` TI SNOS412Q, LM1117-ADJ:

| Parameter | Value |
|---|---|
| V_REF (OUT→ADJ) | 1.25 V typ; 1.238–1.262 V @ 25 °C; 1.225–1.27 V over 0–125 °C |
| I_ADJ | 60 µA typ, 120 µA max |
| Minimum load current | 1.7 mA @ 25 °C, **5 mA over full temperature range** |
| Output capacitor | ≥ 10 µF, **ESR 0.3 Ω to 22 Ω**, tantalum named explicitly |
| Dropout @ 800 mA | 1.2 V @ 25 °C, 1.3 V over temp |

`[CALC]` with R4 = 121 Ω (OUT→ADJ), R5 = 887 Ω (ADJ→GND):

```
V_OUT = V_REF × (1 + R5/R4) + I_ADJ × R5
      = 1.25 × (1 + 887/121)   + 60 µA × 887
      = 1.25 × 8.3306          + 0.0532
      = 10.413 + 0.053         = 10.47 V   (nominal)
```

Worst-case stack (V_REF at its 0–125 °C limits, both resistors at ±1 %, I_ADJ 60–120 µA):

```
  low   1.225 × (1 + 7.3306×0.9803) + 0.053  ≈  10.08 V
  high  1.270 × (1 + 7.3306×1.0202) + 0.107  ≈  10.88 V
```

**Both extremes satisfy R1 (≥ 9 V) with wide margin and stay well under 12 V.** The design is
robust precisely because the requirement is a window. ⚠️ Note the upper bound of 10.88 V
brushes the top of the "~9.5–11 V is correct" band stated in `docs/aF4-reference.md`; it is still
inside it, but there is less headroom above than the round number 10.4 V suggests.

### 2.2 Load on the 10.4 V rail

`[CALC]`, using V_OUT = 10.47 V and datasheet LED forward voltages:

| Branch | Expression | Current |
|---|---|---|
| R4 + R5 divider | 10.47 / 1008 Ω | **10.39 mA** |
| D3 green via R6 | (10.47 − 2.2) / 1000 Ω | **8.27 mA** |
| **Quiescent total** | | **18.7 mA** |
| R3 bleed (only while asserted) | 10.47 / 100 kΩ | 0.10 mA |
| D5 yellow via R7 (only while asserted) | (10.47 − 2.0) / 6800 Ω | 1.25 mA |
| **Total during a feed** | | **20.0 mA** |

Consequences:

- **Minimum load is satisfied by the divider alone** (10.39 mA vs the 5 mA requirement).
  D3's branch is a bonus, not load-bearing. Earlier project notes implied D3 carried this;
  it does not, and it must not be relied on. `[AUDIT]` Strictly the current *through R4* is
  V_REF/R4 = 10.33 mA (10.02 mA at worst-case tolerance) rather than V_OUT/1008 — same
  conclusion against the 5 mA floor, slightly different physics, and worth stating because
  this branch **is** the minimum-load guarantee.
- **`[AUDIT]` R5 is the hottest passive on the board.** It drops 9.22 V at 10.39 mA =
  **~96 mW against an 0805's 125 mW rating — 77 %**. Acceptable at enclosure temperatures,
  but it has no margin for a hot day and this document did not previously mention it. A
  0.25 W-rated 0805 is a drop-in if the margin is wanted. Note that **raising the divider
  impedance is not available** — the divider is the minimum-load ballast.
- **F1 margin:** 20 mA against a 0.10 A hold current — 5× margin `[DS]`.
- **U2 dissipation:** with the SS14 dropping ~0.35 V, U2 sees ~11.65 V in, so
  (11.65 − 10.47) × 18.7 mA ≈ **22 mW**. No thermal concern. ⚠️ The 0.35 V Schottky drop
  at ~20 mA is an estimate, not read off the SS14 forward-voltage curve. `[ASSERT]`
- **Headroom — `[AUDIT]` the earlier reasoning here was wrong.** This document previously
  argued "1.2 V dropout is specified at 800 mA, so at 20 mA it is far smaller." That is
  true of a PMOS LDO and **false of the LM1117**, which is a quasi-LDO with an NPN pass
  device: its dropout is a V_BE stack and the dropout-vs-current curve is nearly **flat at
  ~1 V**. Redone honestly, with the SS14 at ~0.3 V:

  | Brick | LDO input | Headroom to 10.47 V | Headroom to worst-case 10.88 V |
  |---|---|---|---|
  | 12.2 V | 11.90 V | 1.43 V ✓ | 1.02 V — at the edge |
  | 12.0 V | 11.70 V | 1.23 V ✓ | 0.82 V — **in dropout** |
  | 11.6 V | 11.30 V | 0.83 V — **in dropout** | 0.42 V — deep in dropout |

  **This is not a safety problem.** In dropout the LM1117 degrades gracefully to
  V_IN − ~1 V ≈ 10.3–10.7 V, still inside the 9–11 V window, so the feeder still triggers.
  What is lost is regulation and ripple rejection, not function. But two consequences
  follow: a board whose divider stacks toward the high end rides dropout on a nominal
  12 V brick; and **commissioning checks 6.2 and 6.3 are mutually inconsistent at their
  edges** — a brick legitimately passing 6.2 at 11.6 V cannot deliver 10.3 V at TP2 even
  with perfect parts. If 6.3 reads low after a low-but-passing 6.2, the divider is
  probably innocent.

### 2.3 PhotoMOS drive

`[DS]` Panasonic AQY212GS:

| Parameter | Value |
|---|---|
| LED forward voltage | 1.32 V typ, 1.5 V max |
| Recommended LED current | 5 mA min, 30 mA max |
| Load rating | 60 V, 1.0 A continuous |
| On-resistance | 0.34 Ω typ, 0.7 Ω max |
| Turn-on / turn-off | 1.3 ms typ (5 ms max) / 0.1 ms typ (0.5 ms max) |
| Isolation | 1500 Vrms |

`[CALC]` with R1 = 220 Ω from GPIO32:

```
  nominal    (3.3 − 1.32) / 220 = 9.0 mA
  worst case (3.0 − 1.5)  / 220 = 6.8 mA
```

Both inside the recommended 5–30 mA band, with 36 % margin at worst case. ESP32 GPIO source
current of 9 mA is well within its ~20 mA recommended / 40 mA absolute limit.

Switching time (1.3 ms typ) is irrelevant against a 20 s pulse.

### 2.4 The GPIO13 problem — why the trigger is on GPIO32

`[CAD]` The Olimex board has **R35, a factory 2.2 kΩ pull-up to +3.3 V on GPIO13** (the I²C
SDA pull-up), confirmed in the Rev N KiCad source. Not optional, not removable without rework.

During reset and early boot GPIO13 is high-impedance. `[CALC]` solving the node — 3.3 V through
2.2 kΩ, into R2 (10 kΩ to GND) in parallel with the R1 + LED branch:

```
  node settles ≈ 1.4 V
    in  via pull-up   (3.3 − 1.4)/2200  = 0.86 mA
    out via R2         1.4/10000        = 0.14 mA
    out via R1 + LED  (1.4 − ~1.25)/220 ≈ 0.68 mA   ← into the PhotoMOS LED
```

0.68 mA against an AQY212 operate current of ~1.1 mA typical is **62 % of the way to a
spurious feed**, before any firmware runs. `restore_mode: ALWAYS_OFF` cannot help — the pin
is high-Z before firmware exists. The failure mode is "10.4 V on the trigger port for more
than 6 seconds = an unscheduled feed into a reef tank."

> **`[AUDIT]` RESOLVED — and the truth is worse than the paragraph above.** Panasonic's
> published spec `[DS]`:
>
> | Parameter | Value |
> |---|---|
> | LED operate current | **1.1 mA typ, 3 mA max** |
> | LED **turn-off** current | **0.3 mA min**, 1.0 mA typ |
> | Recommended LED operating range | 5–30 mA |
>
> The ~1.1 mA figure was right. But the number that actually governs is the one this
> document never cited: **the guaranteed-off threshold is 0.3 mA**, and there is no
> minimum operate current — below 1.1 mA the datasheet simply stops promising the relay
> stays open. Re-solving the boot node with a realistic sub-milliamp LED V_F of
> 1.0–1.25 V gives **0.72–0.85 mA**, higher than the 0.68 mA above and **more than 2× the
> guaranteed-off current**.
>
> "62 % of the way to a spurious feed" understated it. On GPIO13, nothing guaranteed the
> feed *wouldn't* happen. Moving to GPIO32 was not cheap insurance — it was mandatory.

`[CAD]` **GPIO32** touches only the ESP32 module and EXT2 pin 6 — no pull-up, no strapping
function, not shared with UEXT. GPIO33 is nearly as clean (one unpopulated resistor).

### 2.5 Protection

| Ref | Part | Function | Notes |
|---|---|---|---|
| D1 | SS14 Schottky 40 V / 1 A | Reverse polarity, in series with +12 V | New in rev D; rev C had **none**. Costs ~0.35 V of headroom |
| D2 | SMAJ13A, 400 W unidirectional | Input transient clamp | 13 V standoff, 21.5 V clamping `[DIST]` |
| D4 | SMBJ13CA, 600 W bidirectional | Clamp across the trigger pair at J2 | 13 V standoff, breakdown 14.4–15.9 V `[DIST]`. No orientation |
| F1 | 1206L010/60WR PPTC | Overcurrent on the 12 V tap | 0.10 A hold / **0.25 A trip** / 60 Vdc, −40…+85 °C `[DS]` |
| R3 | 100 kΩ bleed | Guarantees the 0 V re-arm (R2 above) | 0.10 mA |

✅ **CLOSED `[MEAS] 2026-09-01`.** Both TVS parts have a 13 V standoff on a nominally
12 V rail. The brick measures **12.13 V open-circuit, stable** — comfortably below the
standoff, so D2 never conducts at idle and no part change is needed.

Loaded, the rail sits at **11.84–11.86 V** and dips to **11.77 V** during a feed, so the
standoff is even further away in service. Separately, the port itself tolerates the OEM
dongle's **16.40 V** turn-on overshoot on every feed, which makes the worst-case 10.88 V
output look tame.

**Deliberately absent:** a series resistor on the trigger tip. At 10.4 V into a short it
would sit right at the polyfuse hold current and cook rather than trip. The LDO's internal
current limit plus F1 handle a shorted tip properly. `[CALC]`

### 2.6 Indicator LEDs

`[DS]` Both are Kingbright 0805, both **water clear**:

| Ref | Part | Intensity @ 20 mA | V_F | λ | Angle |
|---|---|---|---|---|---|
| D3 green | APT2012SGC | 12 mcd typ, **5 mcd min** | 2.2 V typ, 2.5 max | 565 nm | 160° ⚠️ |
| D5 yellow | APT2012SYCK | 150 mcd typ, 80 mcd min | 2.0 V typ, 2.5 max | 590 nm | 140° ⚠️ |

⚠️ `[AUDIT]` **Unresolved conflict on viewing angle.** The figures above are read off the
Kingbright datasheet PDFs; the audit found 120° for both from two distributor-datasheet
sources. Neither resistor value depends on it — it changes only how wide the cone through
the lid sight holes is. Settle it against the current Kingbright drawing if it matters.

The two parts differ **~12× in efficiency**. `[CALC]` scaling intensity linearly with current:

| | Current | Intensity (typ) | Intensity (worst case) |
|---|---|---|---|
| D3 via R6 = 1.0 kΩ | 8.27 mA | ~5.0 mcd | ~2.1 mcd |
| D5 via R7 = 6.8 kΩ | 1.25 mA | ~9.3 mcd | ~5.0 mcd |

Reasonably matched to the eye. ⚠️ Linear intensity-vs-current scaling is an approximation
`[ASSERT]`; real LEDs are sub-linear at high current and roughly linear at low, so these
figures are fair-to-slightly-optimistic at the low end.

Both are viewed through **Ø3.5 mm sight holes in the lid**, which is why absolute brightness
matters here at all.

> **This was a defect, caught 2026-08-28.** R6 and R7 originally shared a single 10 kΩ value,
> giving 0.82 mA and putting D3 at ~0.5 mcd — effectively invisible. Root cause: 10 kΩ was
> chosen as a jellybean value without checking it against the LEDs' actual intensity specs.

---

## 3. Bill of materials — with verification status

Board BOM: **20 lines, 21 placements** (17 SMD + 4 THT / 28 joints). Every manufacturer part
number below was confirmed against a live distributor listing on 2026-08-28, and independently
re-confirmed by the audit the same day.

| # | Ref | MPN | Description | Status |
|---|---|---|---|---|
| 1 | U1 | Panasonic **AQY212GS** | PhotoMOS SSR, SOP-4, 60 V / 1 A, 1500 Vrms | `[DIST]` ✓ |
| 2 | U2 | TI **LM1117MPX-ADJ/NOPB** | LDO, SOT-223, adjustable, 800 mA | `[DIST]` ✓ |
| 3 | D1 | Vishay **SS14-E3/61T** | Schottky 40 V / 1 A, SMA | `[DIST]` ✓ |
| 4 | D2 | Littelfuse **SMAJ13A** | TVS 400 W unidirectional, SMA | `[DIST]` ✓ |
| 5 | D4 | Littelfuse **SMBJ13CA** | TVS 600 W bidirectional, SMB | `[DIST]` ✓ |
| 6 | D3 | Kingbright **APT2012SGC** | LED green 565 nm, 0805 | `[DIST]` ✓ |
| 7 | D5 | Kingbright **APT2012SYCK** | LED yellow 590 nm, 0805 | `[DIST]` ✓ **corrected** |
| 8 | F1 | Littelfuse **1206L010/60WR** | PPTC 0.10 A / 0.25 A / 60 V, 1206 | `[DIST]` ✓ **corrected** |
| 9 | C1 | Murata **GRM31CR61H106KA12L** | 10 µF 50 V **X5R** 1206 | ⚠️ `[AUDIT]` **EOL at Murata (2020)**, but DigiKey ships today and distributor float is ~1.6 M. Fine for 5 boards; expect PCBWay to flag it. Line up a current-production substitute from a **live parametric search**, never from memory |
| 10 | C2 | Kemet **T491B106K025AT** | 10 µF 25 V tantalum, EIA-3528 B, ESR ~2 Ω | `[DIST]` ✓ |
| 11 | R1 | Yageo **RC0805FR-07220RL** | 220 Ω 1 % | `[DIST]` ✓ |
| 12 | R2 | Yageo **RC0805FR-0710KL** | 10 kΩ 1 % | `[DIST]` ✓ |
| 13 | R3 | Yageo **RC0805FR-07100KL** | 100 kΩ 1 % | `[DIST]` ✓ |
| 14 | R4 | Yageo **RC0805FR-07121RL** | 121 Ω 1 % | `[DIST]` ✓ |
| 15 | R5 | Yageo **RC0805FR-07887RL** | 887 Ω 1 % | `[DIST]` ✓ |
| 16 | R6 | Yageo **RC0805FR-071KL** | 1.0 kΩ 1 % | `[DIST]` ✓ **new** |
| 17 | R7 | Yageo **RC0805FR-076K8L** | 6.8 kΩ 1 % | `[DIST]` ✓ **new** |
| 18 | J1 | Same Sky **PJ-079BH** | DC jack 5.5 × 2.5, 2.5 mm centre pin, 24 V / 5 A | `[DIST]` ✓ |
| 19 | J2 | Same Sky **SJ1-3523N** | 3.5 mm jack, 3-conductor, right angle | `[DIST]` ✓ |
| 20 | J3, J4 | Sullins **PPTC101LFBN-RC** ×2 | 1×10 socket, 2.54 mm | `[DIST]` ✓ |

### 3.1 Sourcing traps recorded

- **J1:** `PJ-002AH` / `PJ-102AH` look identical but are 2.0–2.1 mm centre pin. Only the
  **"B" suffix** parts are 2.5 mm. The same trap applies to the 12 V splitter cable.
- **C2 must stay tantalum.** The LM1117 requires output-cap ESR between 0.3 Ω and 22 Ω `[DS]`.
  A low-ESR ceramic substitution risks loop instability.
- **C1 is X5R, not X7R.** Murata makes no 10 µF 50 V X7R in 1206; that C/V needs a 1210.

### 3.2 Bought separately (not on the board)

Olimex ESP32-POE-ISO (~$28–35) · 2× 1×10 male headers for EXT1/EXT2 (ship unpopulated) ·
12 V barrel Y-splitter 5.5 × 2.5 centre-positive · 3.5 mm male–male patch cable ·
PETG for the enclosure · M2 / M3 self-tapping screws.

---

## 4. Board

| Property | Value |
|---|---|
| Size | 57.00 × 50.00 mm, rectangular |
| Layers / thickness / copper | 2 / 1.6 mm / 1 oz |
| Finish | ENIG preferred, HASL acceptable |
| Min track / space | 0.35 mm / 0.20 mm |
| Min drill | 0.45 mm (stitching vias) |
| Plated slots | **0.70 mm minimum**, deliberately widened |
| Placements | 17 SMD (top face) + 4 THT parts / **28** joints `[AUDIT]` |
| THT mounting side | J1, J2 bodies on the **top** face. **J3, J4 bodies on the BOTTOM face**, soldered on top — see §A3. The fab data does not express this; it must be stated by designator in the fab note |
| Mounting | 2 × M3 at (123.0, 118.0) and (123.5, 147.0), board frame |

`pcb/gen_pcb.py` is the source of truth — it generates the `.kicad_pcb` deterministically from
named coordinates taken from the Olimex Rev N source `[CAD]`, so socket alignment is exact by
construction. **Edit the script, not the board file.**

### 4.1 Geometry from vendor CAD `[CAD]`

| Feature | Position (Olimex board frame) |
|---|---|
| ESP32-POE-ISO outline | x 90.15–118.15, y 90.00–188.15 (28.00 × 98.15 mm) |
| EXT1 pin 1 | (91.44, 123.22), 2.54 mm pitch |
| EXT2 pin 1 | (116.84, 123.22), 2.54 mm pitch |
| GND | EXT1 pin 3 → (91.44, 128.30) |
| GPIO32 | EXT2 pin 6 → (116.84, 135.92) |

### 4.2 Verification status of the board

✅ **Independently re-run 2026-08-31** (`archive/reviews/aF4-prefab-review-2026-08-31.md`), on KiCad
7.0.11 with the zones filled from scratch — the counts below are confirmed, not reported.
DRC via `pcbnew.WriteDRCReport` (KiCad 7): clearance 0, courtyard
overlaps 0, hole clearance 0, hole-to-hole 0, copper-to-edge 0, unconnected 0, mask bridges 0.
That review also swept clearance at multiple rules on the filled board: **zero violations at
0.2032 mm (8 mil) and at 0.24 mm; first hits at 0.25 mm**, so the real minimum copper gap is
0.24–0.25 mm and the 0.20 mm carried in these docs is the KiCad netclass default, not the
geometry. The shipped Gerbers were re-exported and diffed against the board — identical.
Remaining flags are silkscreen cosmetics and "library footprint differs", both expected for
programmatically placed footprints.

**A defect DRC does not catch, found by inspecting the drill file:** KiCad's SJ1-3523N
footprint specifies 0.40 mm plated slots and PJ-079BH 0.60 mm — both below fab routing
minimum (~0.5 mm drilled / 1.0 mm milled). `pcb/gen_pcb.py` now enforces `MIN_SLOT = 0.70 mm` and
prints what it widened. Worst-case annular ring after widening is 0.25 mm.

> **Generalised lesson:** DRC checks what it was told to check. Slot widths, and any
> hand-written count in a generated document, are outside it. Inspect the drill tool list
> before any package leaves the building.

### 4.3 Isolation

Two separate ground pours with **no copper crossing**. The only connection is U1 itself,
straddling the boundary; its pad-to-pad gap is **4.80 mm**. The band is marked on both
silkscreens, and the two mounting holes sit inside it — both **NPTH, no copper**.

`[AUDIT]` The **true minimum logic-to-power creepage is 4.425 mm**, and it is not set by U1:
**R1 pad 2** reaches x 121.925, 0.275 mm inside the nominal band, against the GNDP pour edge
at 126.350. Measured off the regenerated board. The earlier "4.3 mm" figure was an artefact
of the wrong U1 footprint and is withdrawn (§A1).

⚠️ **Assembler instruction that must survive:** no copper, vias or stitching in that band.

### 4.4 The ordered board re-checked on KiCad 9.0.7 `[MEAS] 2026-09-17`

Kenny asked whether a board made with KiCad 7-era tools holds up under current ones. Everything
below ran on the Mac against **copies** in the session scratchpad; nothing in `pcb/` was
regenerated or rewritten. It is a check of what was ordered, not a change — rev E is spent.

**What was checked against what.** The uploaded package is `pcb/af4-trigger-hat-rev-E-GERBERS.zip`
(`pcb/pcbway-order-YB1800644.md`). Its eleven fab files are byte-identical to `pcb/gerbers/`.
The committed `.kicad_pcb` (file format 20221018, KiCad 7) loads in KiCad 9 without complaint.

| Check | KiCad 9.0.7 result |
|---|---|
| DRC, zones as shipped | **0 errors, 0 unconnected.** 33 warnings, all silkscreen: 16 silk overlap, 8 silk-to-edge, 7 silk over copper, 2 text height — the same 33 as the KiCad 7 `pcb/drc.rpt` |
| The KiCad 7 report's other 28 | `lib_footprint_issues` — not raised under `kicad-cli` with no footprint library table. Expected for generated footprints, not a finding |
| Zones refilled by KiCad 9's filler | GNDP 633.844 → 633.876 mm², GNDL 1467.197 → 1467.252 mm², same island counts. DRC after refill identical |
| Clearance sweep, custom rules | **0 at 0.24 mm, 1 at 0.25 mm** — minimum copper gap **0.245 mm**, GPIO32 track to J3 pad 4. Matches §4.2 exactly |
| Isolation, logic nets (GNDL, GPIO32, LED_A) to power copper | **4.425 mm clearance and 4.425 mm creepage** (KiCad 9's creepage constraint), set by R1 pad 2 to the GNDP pour edge at x 126.35, confirmed from pad geometry. GNDL pour to GNDP pour 4.70 mm. Matches §4.3 |
| Netlist read back from the board | Matches §2 net for net: F1 → D1 → +12V; D2 TVS +12V–GNDP; U2 pin 1 ADJ, pin 2 + tab 10V4, pin 3 12V; R4 121 Ω / R5 887 Ω; U1 pins 1/2 LED_A/GNDL, 3/4 TIP/+10V4; R2 GPIO32–GNDL; J3.3 = GNDL, J4.6 = GPIO32; D3/D5 pad 1 on GNDP |
| KiCad 9 Gerber export vs the shipped Gerbers | **Pixel-identical on all nine layers** (both coppers, masks, pastes, silks, edge), rasterised at 0.025 mm. Control: the same comparison against KiCad 9-*refilled* copper shows 2,000+ differing pixels, so the method sees sub-0.05 mm pour changes |
| KiCad 9 drill export vs the shipped `.drl` | **Identical**: the same 7 tools (0.45–3.20 mm), the same 47 hits and slots, narrowest slot 0.70 mm (§4.2) |

**Conclusion:** the tool generation changed nothing that reached the fab. The ordered board is the
board the §4.2 audit verified.

**A KiCad 9 report quirk, not a board fault:** the isolation rule reported its 4.425 mm pair as
"Pad 2 [PWRLED] of R6". R6 sits at x 135–137, on the power side; the pad geometry puts the real
pair at R1 pad 2. Read positions from a KiCad 9 DRC item before trusting its item label.

**What this does not cover:** the J3/J4 mounting face (item 24 — the file is wrong, the rework
fixed the parts), the "10s pulse" silkscreen (item 19), D3/D5 physical polarity (item 25), and
assembly quality on the four unphotographed boards (item 26). None is a tool question. Board-level
DRC also cannot catch the enclosure-side cap collision; that is §6.3's job.

---

## 5. Firmware

`firmware/af4-feeder.yaml` in the repo is the source of truth. The ESPHome Device Builder (Docker on
the Unraid server, port 6052) holds its own copy — changes must be pasted there manually,
then Install → Wirelessly.

### 5.1 The safety architecture

All feeder timing rules are enforced **on-device**. Home Assistant is scheduler only — it
presses one button and can do nothing else.

| Mechanism | Purpose |
|---|---|
| `switch.feed_ssr` is `internal: true` | HA cannot reach the raw GPIO line at all |
| `restore_mode: ALWAYS_OFF` | software half of the boot-safety pair |
| R2 10 kΩ pulldown on GPIO32 | hardware half — **unopposed** on GPIO32, which is the point |
| `script.do_feed` with `mode: single` | re-entrant presses are **dropped**, not queued |
| `button.af4_feed` template button | the sole exposed control |
| `binary_sensor.af4_lockout` | exposes lockout state for dashboards and automation conditions |
| `globals.feed_in_flight`, `restore_value: yes` | **flash-persisted**, so a reboot inside a cycle is detected on boot |
| `script.boot_recovery` off `on_boot` | serves a 300 s lockout when that flag comes back true |
| `web_server: auth:` | the local control page is no longer an anonymous second control path |

### 5.2 Timing check against the spec `[CALC]`

```
  20 s pulse    ≥ 15 s threshold hold      ✓  (33 % margin)   <-- live on the device
 290 s off tail ≥ 60 s re-arm              ✓  (383 % margin)
 20 + 290 = 310 s total cycle ≥ 5 min      ✓  (10 s of margin, was exactly 0)
```

✅ **RESOLVED AND FLASHED 2026-09-01.** Two separate problems were
closed in one edit. The old block read `≥ 6 s` and claimed a 67 % margin; against inD's
actual figures the 10 s pulse had none, so the pulse went to **20 s**. And the audit's
zero-margin complaint — R3 requires feeds ≥ 5 min apart and the cycle was exactly 300 s —
was closed by keeping the **290 s tail** rather than trimming it to 280 s, which buys the
310 s cycle for free.

Everything in this section describes the firmware **as actually running**: the device
reports its build as 2026-09-01 18:54:20, and the last YAML commit that evening was
18:51:33. It was installed three minutes after it was written. A second install on
2026-09-02 18:15:49 carried the rotated credentials and nothing else.

### 5.3 ✅ `[AUDIT]` The lockout did not survive a reboot — CLOSED 2026-09-01

`script.do_feed`'s state lives in RAM. Any reboot inside the 300 s cycle — OTA update,
crash, brownout, power blip — clears the lockout silently. The switch comes back
`ALWAYS_OFF`, so the pin is safe, but `binary_sensor.af4_lockout` reads `off` and the
device accepts a new press immediately.

A sequence that ends with two feeds ~2 minutes apart into the tank: scheduled feed fires →
OTA or crash at t+60 s → HA retry, second schedule slot, or a manual press → second feed.
Low probability, but it is exactly the class of unattended edge this document exists to
catch.

**Fix, implemented:** a `restore_value: yes` global, `feed_in_flight`, is set when the
pulse starts and cleared when the lockout ends. It lives in flash, so a reboot mid-cycle is
detected in `on_boot`, which runs `script.boot_recovery` — a 300 s lockout-only script. The
Feed button checks `boot_recovery.is_running()` and ignores presses while it is, and
`binary_sensor.af4_lockout` ORs both scripts so the state is visible. A clean boot leaves
the flag false and costs nothing.

⚠️ One practical wrinkle, verified 2026-09-01: the `on_boot` log line fires while ethernet
is still coming up, so **no log client ever sees it** and ESPHome does not replay it. Read
the *state* instead — Feed Lockout on at a low uptime with nobody having pressed Feed is
the recovery lockout. `docs/aF4-assembly-guide.md` §6 says so at the point of use.

### 5.4 ✅ `[AUDIT]` The web server was a second, unauthenticated control path — CLOSED 2026-09-01

`web_server: port: 80` exposes the Feed button to anything on the LAN, with no `auth:`
block. The safety story above — "HA is scheduler only, it presses one button and can do
nothing else" — is true of Home Assistant and **false of the network**. On a home LAN this
was a judgment call rather than a defect, but the document should have said so.

`web_server:` now carries an `auth:` block. Commissioning step 6.5 uses this page, so the
assembly guide records the credential at the point of use; Home Assistant is unaffected
because it talks over the API, not this page.

### 5.5 ✅ The related hygiene problem — the worse one — CLOSED 2026-09-02

The API encryption key, the OTA password **and the new web_server password** were all
committed in plaintext to a **public** GitHub repository. Adding web auth and publishing
its password in the same commit closed nothing; it moved the hole from the LAN to the
internet.

All three now resolve through `!secret` against a gitignored `firmware/secrets.yaml`, **and all
three were rotated** — which is the part that actually remediates it, because git history
keeps the old values whatever the working tree says. History was deliberately *not*
rewritten: rotation makes the exposed values worthless, and a filter-repo pass would
rewrite all 46 commit SHAs while GitHub can still serve cached objects. Decided 2026-09-02.

Two operational consequences, both recorded at the point of use in
`docs/aF4-assembly-guide.md` §4: the ESPHome Device Builder needs **its own copy** of
`firmware/secrets.yaml`, and the first install after the rotation authenticates with the **old**
OTA password while installing the new one.

### 5.6 `[AUDIT]` Held-high failure modes are bounded — the design's best safety property

Checked deliberately, since "unscheduled feed" is the nightmare. If the ESP32 crashes with
the SSR on, or the PhotoMOS fails shorted, the port sees a **continuously held** 10.4 V.
Per R2, re-arming requires ~0 V for more than 60 s — so a held-high line produces **at most
one feed and then never re-arms**.

Every stuck-at fault therefore costs one feed, not a feeding loop. This is the single best
safety property the design has, and it emerges from the feeder's own spec rather than from
anything on the board.

### 5.7 Home Assistant integration

Entities — **seven**, re-read from HA 2026-09-18: `button.af4_feeder_feed` (sole control),
`button.af4_feeder_restart`, `binary_sensor.af4_feeder_feed_lockout`,
`binary_sensor.af4_feeder_status`, `sensor.af4_feeder_ip_address`, `sensor.af4_feeder_uptime`,
`sensor.af4_feeder_esphome_version`. ⚠️ This list said six until 2026-09-18; the version
sensor was always there and was simply never written down.

Helpers: `input_boolean.reef_af4_schedule_enabled` (master kill switch),
`input_datetime.reef_af4_feed_time_1` … `_6`, `input_number.reef_af4_feeds_per_day`,
`counter.reef_af4_feeds_today`, `sensor.reef_af4_next_feed`.

Consumers of the aF4 entities — **four, plus a dashboard**, re-read 2026-09-18:
`automation.reef_tank_af4_scheduled_feed` (scheduler + per-feed confirmation),
`automation.reef_tank_feeder_health_watchdog` (backstop, shared with the Plank feeder),
`automation.reef_circulation_pause_powerheads_for_feeding` (triggers on the lockout edge —
**not previously recorded here**), `automation.reef_tank_reset_ato_counter_daily` (nightly
counter reset), and the **Reef Command** dashboard (`reef-command`).

**Every one keys on `entity_id`, not `device_id`** — verified 2026-09-18. That is what makes
a board swap survivable; see §11.

#### `automation.reef_tank_af4_scheduled_feed` — read from HA 2026-09-02

Materially more than "presses a button", which is all this document used to say. Triggers
on **six** `input_datetime` helpers so times stay dashboard-editable, each slot gated by
`input_number.reef_af4_feeds_per_day` — slot N is inert while the count is below N — then,
behind the master kill switch:

1. **Two interlocks before pressing.** `binary_sensor.af4_feeder_feed_lockout` must be
   `off`, and `binary_sensor.reef_tank_sump_return_pump_..._running` must be `on`. The
   second is the one this document never knew about: the feeder discharges into the sump,
   so with no return pump the food never reaches the display. It reads `off` while the
   system is unplumbed and self-clears when the return comes up.
2. **Press, then wait up to 15 s for the lockout to go `on`.** On-device the lockout is
   `do_feed.is_running() || boot_recovery.is_running()`, and the press only happens while
   it is `off` — so **the lockout turning on is proof the pulse started**. That is as close
   to feed confirmation as an input-only port allows.
3. **The counter increments only on a confirmed pulse.** An unacknowledged press notifies
   and is deliberately *not* counted, so a press lost in transit cannot log a phantom feed
   and blind the watchdog below. This is load-bearing and must survive any rewrite.
4. **Both failure paths notify**, naming which interlock failed.

#### `automation.reef_tank_feeder_health_watchdog` — read from HA 2026-09-02

The backstop for silent failure, in three branches:

- **23:45 daily check.** Compares each feeder's counter against how many of its feed times
  have actually elapsed today, computed from the `input_datetime` helpers rather than
  hardcoded — so moving a feed time cannot false-alarm. 23:45 is late enough that any
  plausible feed time has passed and early enough to beat the midnight counter reset.
- **aF4 board offline 15+ minutes** while the schedule is enabled. Gated on the toggle, so
  bench and case work with the schedule off stays quiet.
- **Plank plug Z-Wave node dead** 15+ minutes.

Three deliberate choices worth preserving:

1. **Feed counting lives in HA, not on-device** — it survives ESP32 reboots and reuses the
   existing nightly reset automation.
2. **The lockout condition does double duty.** `off` means the device is reachable *and*
   outside its lockout, so an offline ESP32 skips the feed rather than firing a button
   press into the void. Offline reads `unavailable`, which fails the check correctly.
3. **The counter counts confirmed pulses, not presses.** See point 3 above.

Networking: IP 192.168.1.55 reserved in OPNsense dnsmasq against Ethernet MAC
`00:70:07:7F:48:C3` (host override `af4-feeder`, MAC match only, no client identifier). The
board pulled a new DHCP lease after flashing, which broke HA's cached discovery with
`Errno 113`; the reservation is the fix.

**No feedback channel exists, and this is now the only unmonitored failure direction.**
The 0-10 V port is input-only, so everything above confirms that *the pulse was sent* and
nothing confirms *that food came out*. The gap that matters is an over-temperature fault:
per inD's own documentation it stops the feeder and **never self-clears**, and it is
invisible to us — the ESP32 would pulse happily, the lockout would assert, the counter
would increment, and the 23:45 watchdog would stay silent while the tank went unfed.

A power-monitoring smart plug on the 12 V supply is the only way to close it without
opening the unit: feed-motor current is the sole dispense evidence available. Open item 20.

---

## 6. Enclosure

**External 65.2 × 117.0 × 39.9 mm**, PETG, printed with no supports. (38.4 mm until the
1.5 mm hat lift of 2026-09-16, §6.3.)
`hardware/enclosure/af4_enclosure_ocp.py` is the parametric source and runs dimensional checks plus
solid-interference tests before exporting. Since 2026-09-16 the scalar checks pass at the lifted
height; ⚠️ the solid tests and exports have **not** been re-run (§6.3, item 27).

### 6.1 The vertical stack — the governing dimension

```
  z = -11.90   case floor, outside
  z =  -9.50   case floor, inside
  z =   0.00   top of the three ESP32 standoffs = ESP32 bottom face
  z =   1.58   ESP32 top face
  z =   4.12   top of the male header plastic on EXT1/EXT2
  z =   5.62   socket bottoms — float 1.50 mm above the plastic (HAT_LIFT)
  z =   9.96   male pin tips → ~4.3 mm into the sockets
  z =  11.20   top of UEXT1 box header   [MEAS]  → 2.92 mm clear
  z =  11.50   top of DCDC1 power module  [MEAS]  → 2.62 mm clear
  z =  13.40   top of the electrolytic cap beside DCDC1  [MEAS]  ← tallest thing under the hat
  z =  14.12   hat underside                       → 0.72 mm clear of the cap
  z =  15.72   hat top face
  z =  18.22   3.5 mm jack axis
  z =  19.32   barrel jack axis
  z =  22.92   barrel jack crown            → 2.08 mm clear of the lid
  z =  25.00   lid underside
```

**Revised 2026-09-16 — see §6.3.** The table this replaced put the UEXT box header at 5.98 and
called it the tallest thing under the hat. Calipers put it at 11.20, and put an electrolytic
cap at 13.40 — **0.78 mm into the hat as then designed.** The hat now sits 1.50 mm higher.

**The socket body height plus `HAT_LIFT` sets everything.** Substitute a different socket →
change `HAT_Z` and re-run; the script reports what now collides. The three `[MEAS]` rows are
`TALL_PARTS` in the script and are the check that matters.

⚠️ **This table is also the proof that J3/J4 mount from the BOTTOM face.** The 10.00 mm
between the header plastic (4.12) and the hat underside (14.12) is the 8.50 mm socket body
plus the 1.50 mm lift. Nothing in the stack sits between 14.12 and 15.72 except the board
itself. Build the sockets on top and the hat cannot reach the pins at all. See §A3.
(Before 2026-09-16 the same argument read 8.50 mm between 4.12 and 12.62.)

### 6.2 Two details that are easy to lose

- The barrel-jack hole needs its **Ø13 × 1.8 mm counterbore on the outside**, thinning the
  wall to 1.2 mm locally. Without it, 3 mm of wall eats most of the jack's 9.5 mm insertion
  depth. As built the plug engages 6.9 mm.
- The **four Ø3.5 mm LED sight holes** in the lid, each fitted with a 3 mm clear acrylic
  **light pipe**, sit over D3 and D5 on the hat and PWR1 and LNK1 on the Olimex board. This
  is the entire reason LED brightness is a real requirement rather than a cosmetic
  preference (§2.6). The pipes exist because the Olimex LEDs are 21.2 mm below the lid — a
  plain hole gives them a 4.7° viewing half-angle, visible only dead-on. ACT1 and CHRG1
  deliberately have no hole: ACT1 sits 0.361 mm inside the hat footprint and is blindfolded
  by opaque FR4. Full spec in `docs/aF4-enclosure-notes.md`; cutting and fitting in
  `docs/aF4-assembly-guide.md` §1.

Hat mounting holes at (123.0, −118.0) and (123.5, −147.0) are **forced by geometry** — the
only X clearing the ESP32's right edge below (118.15) and the parts column above (from
126.45). Not free choices.

### 6.3 The hat collided with an Olimex capacitor — raised 1.5 mm `[MEAS] 2026-09-16`

**Found 2026-09-16 while dry-fitting headers to a spare ESP32-POE-ISO**, before any rev E
board had arrived. Kenny could force the header plastic in beside DCDC1 but was worried about
the hat's clearance in that corner. The worry was well founded.

**What the design had assumed.** `hardware/enclosure/af4_enclosure_ocp.py` read *"UEXT box hdr
4.40 mm tall (vendor 3D model) — clears the hat easily"*, and §6.1 put the box header's top at
z 5.98 as the tallest thing under the hat. Both checks that could have caught a tall part were
built on that number: the scalar clearance used `1.578 + 4.40`, and the "case vs ESP32" solid
test capped the ESP32's envelope at the same height. **Nothing taller than 5.98 on the Olimex
board was ever tested against the hat.** The vendor mesh was never the problem: parsed on
2026-09-16, it puts UEXT1 at 11.53, DCDC1 at 11.99 and the cap at 13.15.

**Measured, calipers, from the ESP32's bottom face** (= z 0 in the stack, the plane the M2
standoffs stop at). A 5.0 mm reading across the board plus the WROVER can matched the model's
1.58 + ~3.3, which validates the reference face.

| Part | Measured top z | Vendor model | Clearance to hat underside at 12.62 (as designed) | At 14.12 (as fixed) |
|---|---|---|---|---|
| Electrolytic cap beside DCDC1 | **13.4** | 13.15 | **−0.78 — collision** | +0.72 |
| DCDC1 isolated power module | 11.5 | 11.99 | +1.12 | +2.62 |
| UEXT1 box header | 11.2 | 11.53 | +1.42 | +2.92 |

About 5 mm of the cap's diameter sits inside the hat outline (enclosure x 111.5–118.5,
y −161.5 to −155.0, hat edge at −160.0).

**Decision: raise the hat 1.50 mm** (`HAT_LIFT`). `HAT_Z` 12.618 → 14.118 and `IZ1` (lid
underside) 23.50 → 25.00; the standoffs, jack holes, lid bosses and light-pipe lengths all
follow. External height 38.4 → 39.9 mm. The sockets now float 1.5 mm above the header plastic;
the hat is carried by its two M3 standoffs, so nothing bears on that gap. Cost: pin
engagement ~5.8 → **~4.3 mm** (pin tip 9.96, socket bottom 5.62). 1.0 mm was rejected: it
leaves the cap 0.22 mm, inside the tolerance of a leaded cap sitting slightly crooked.
Rejected alternative: swap the cap for a Ø6.3 × 7.7 low-profile part — keeps the case but is
rework on the Olimex board.

⚠️ **Consequence for assembly:** the hat must never be pressed fully home on the headers with
the ESP32 out of the case. Without the standoffs it bottoms on the header plastic at the old
height and lands on the cap. `docs/aF4-assembly-guide.md` §5 says so.

**What changed in the script.** `TALL_PARTS` carries the three measured heights with their
footprints; each gets a ≥ 0.5 mm scalar clearance check, the hat's board slab gets a solid
intersection test against the parts grown 0.5 mm, a pin-engagement check (≥ 3.5 mm) was
added, and the "case vs ESP32" envelope now rises to the tallest measured part. Light pipes:
PoE pair 22.7 → **24.2 mm**, hat pair unchanged at 10.1 mm. `af4_hat_dummy_ocp.py` carries the
same lift.

**Two things this finding does not settle:**

- **The printed case in hand is the 38.4 mm version and must be reprinted.** The exports were
  regenerated on Kenny's Mac later the same day (below). **The lid does not change:** every lid
  feature is positioned relative to `IZ1`, so the origin-translated print file is the same part
  at either height. Confirmed on the regenerated file: same 5,448 triangles, same bounding box,
  every vertex within 0.0023 mm of the old export. → item 27
- **DCDC1 sits ~0.65 mm past the pin-10 end of EXT2 in the vendor model, but the real header
  plastic had to be forced in there.** The hat's J4 socket body is the same length and meets
  the same face. Shave the last half-segment of header plastic rather than force it, and
  dry-fit the hat before soldering. Not asserted by the script, because the model disagrees
  with the part in hand.

**Rejected on the way: mounting the ESP32 bottom side up** so standard Olimex headers point
at the hat. Olimex puts EXT1/EXT2 on `B.Cu`, and flipping the board mirrors the pinout. The
hat's two live pins are EXT1 pin 3 (GND — the only ground on either row) and EXT2 pin 6
(GPIO32); across every flip-and-rotate combination they land on EXT2-3 / EXT1-6,
EXT1-8 / EXT2-5, or EXT2-8 / EXT1-5. **No orientation puts hat ground on a ground pin.** Pin
assignments read from Olimex's `ESP32-PoE-ISO_Rev_N.kicad_pcb` on GitHub.

**A numpy-only verifier was added the same day: `hardware/enclosure/verify_enclosure.py`.** The
OCP script can only agree with itself and cannot run in a session; the verifier reads the STL
files that actually get printed and needs nothing but numpy, so it runs on the Mac, in the
Mac-side session VM (~4 s) and in the cloud container. It checks both bounding boxes, every
standoff top by ray cast, the hat envelope and the ESP32 envelope (up to the tallest measured
part) for case material by ray-parity point-in-mesh — behind a positive control that must find
the floor and walls solid — both jack holes open along their axes, and the hat slab against
`TALL_PARTS` and against the vendor ESP32 mesh sampled across every triangle. **Run against the
committed exports on 2026-09-16:**

- with the **pre-lift** parameters (`git show HEAD~1:…`) every mesh check passes — the exports
  are exactly the 12.618 / 23.50 design, which validates the verifier — and **the vendor-mesh
  check fails, tallest point 13.15 against a hat underside of 12.62.** That is this collision,
  found from the vendor model alone: a check against the part's own model would have caught it
  on 2026-08-27.
- with the **current** parameters it fails five checks — case height 35.40 vs 36.90, both hat
  standoffs at 12.618 vs 14.118, both jack holes blocked on their new axes. **That is the
  acceptance test for item 27: regenerate, then `python3 verify_enclosure.py` must print
  `ALL CHECKS PASSED`.**

Environment rule, per script (from Kenny's 3D-model workflow in another project, which holds
here too): **`af4_enclosure_ocp.py` and `af4_hat_dummy_ocp.py` need `cadquery-ocp` and run only
on Kenny's Mac; `verify_enclosure.py` needs numpy only and runs anywhere.** PyPI is 403-blocked
from both session shells, so "install it and retry" is never the fix in a session.

**Regenerated and verified on Kenny's Mac, 2026-09-16** (`~/.venvs/cad`, Python 3.14,
`cadquery-ocp` 8.0.1). `af4_enclosure_ocp.py`: all geometry checks pass and all six solid tests
read 0.000 mm³, including the new hat-slab-vs-tall-parts test; external 65.2 × 117.0 × 39.9 mm.
`af4_hat_dummy_ocp.py`: all checks pass. `verify_enclosure.py`: **ALL CHECKS PASSED** on the new
exports, re-run independently from the Mac-side session VM. Two things had to be fixed first:

- **OCP 8 broke both scripts.** Static methods lost their `_s` suffix (`TopoDS.Edge_s` →
  `TopoDS.Edge`), `Bnd_Box.Get()` returns an unbound `Limits` struct, and
  `NCollection_Utf8String` became `NCollection_String`. Both scripts now resolve these through a
  small compatibility block (`_static`, `_bbox6`, `_stl_binary`) and run on OCP 7 or 8. → §9.1
- **The dummy script carried its own hand-typed lid height,** `23.50 - (HAT_TOP + J1_H)`, and
  failed at 0.58 mm the moment the enclosure moved — the same class of error as the one this
  section records, one file over. It now reads `IZ1` and `HAT_LIFT` from
  `af4_enclosure_ocp.py` and fails if its own `HAT_LIFT` disagrees. It also looks for a macOS
  font; the committed dummy export has no embossed label, which is cosmetic.

> **Generalised lesson:** a clearance check is only as good as the number it is checked
> against. This one tested the hat against a hand-typed height instead of the vendor mesh
> that was already in `reference/vendor/`, so it passed for three weeks while wrong by 7 mm.
> **Check against the part, or the part's own model — never against a transcribed dimension.**

### 6.4 Lid label turned to read portrait `2026-09-16`

The first printed lid read along the long axis — upright only with the box landscape and the
cable end on the left. Kenny wants it upright with the box **portrait, RJ45 end at the top and
the two jacks on the left**, per a mockup. In the enclosure frame, looking down on the lid, that
is text reading along −X with its top toward −Y: `LID_LABEL_ROT = 180` (the old layout was the
equivalent of 90). Same size, depth and centre; the block now runs across the lid, and the script
asserts its clearance to the lid edge (9.8 mm), the boss counterbores (11.6) and the sight holes
(22.0). **The lid now needs reprinting as well as the case.** Reprinted with the case 2026-09-17. → item 27

`verify_enclosure.py` gained check 6, which exists because a rotation is the kind of change
nobody can verify by reading numbers: it rasterises the engraving out of the exported lid STL at
0.4 mm and scores it against all eight rotations and mirrors of the intended text. On the
existing lid export it reports **rot 90, IoU 0.72**, and 0.04 for the intended 180, which is
the photographed part — so it tells a correct export from a wrong one, including a mirrored one.
**Re-exported on the Mac the same day:** all checks pass, and check 6 reads the new lid as rot 180,
IoU 0.72.

---

## 7. Errors already found and fixed

Listed so an auditor does not spend effort re-discovering them, and because the pattern is
more useful than the individual items.

| Date | Error | Root cause |
|---|---|---|
| 2026-08-28 | **F1 `1206L010/60YR` did not exist** → `/60WR`. Trip current also wrong (0.30 → 0.25 A) | MPN generated from the naming convention (the 1206L suffix is a reel-quantity code) instead of looked up |
| 2026-08-28 | **C1 `GRM31CR71H106KA12L` did not exist** → `GRM31CR61H106KA12L`. X7R → X5R | Same. Murata makes no 10 µF 50 V X7R in 1206 |
| 2026-08-28 | **D5 `APT2012SYC` did not exist** → `APT2012SYCK` | Same |
| 2026-08-28 | **D3 under-driven ~10×** — R6/R7 shared 10 kΩ, putting the green at ~0.5 mcd | Resistor value chosen as a jellybean without checking it against the LEDs' intensity specs |
| 2026-08-28 | Docs claimed **"20 SMD placements"**; actual is 17 | A hard-coded count in a generated document, fixed in the script earlier but left standing in the prose |
| 2026-08-28 | Load and dissipation figures (~15 mA, 17 mW) predated the D3 branch | Derived numbers not revisited after a change to their inputs |
| 2026-08-28 | Claimed a lens mismatch between D3 and D5 | Asserted from naming convention; both are in fact water clear |
| 2026-08-28 `[AUDIT]` | **U1 on a 1.27 mm-pitch footprint; the AQY212GS is 2.54 mm** — board unbuildable | A KiCad footprint picked by name. Its description points at an OPTEK OPIA403 |
| 2026-08-28 `[AUDIT]` | `pcb/gen_pcb.py` said `SMAJ15A` for D2 while everything else said `SMAJ13A` | A value edited in one place and never propagated |
| 2026-08-28 `[AUDIT]` | **"44 joints" was fiction; the real count is 28** — and PCBWay prices hand-soldered joints | A hard-coded count in a generated document, with the correct itemisation printed directly beneath it |
| 2026-08-28 `[AUDIT]` | Circuit diagram showed D2 upstream of D1; the board wires it downstream | Diagram drawn from intent, not from the netlist |
| 2026-08-28 `[AUDIT]` | "Dropout is far smaller at 20 mA" — false for a quasi-LDO | A PMOS-LDO intuition applied to an NPN pass device |
| 2026-09-11 `[EQ]` | **J3/J4 built on the top face; they mount from the bottom** — found in PCBWay's assembly sample photos, boards in rework (§A3) | The mounting side of a THT part is not expressible in Gerbers, absent from an SMD-only centroid, and so survived only in prose — where `PCBWay-README.txt` then contradicted it with "sides populated: top only" |
| earlier | KiCad footprints specified 0.40 / 0.60 mm plated slots, below fab minimum | DRC does not check slot widths |
| earlier | Rev B: three buck modules failed in sequence | A trimpot existed only to hit a precision target the port does not require |

**The dominant failure mode in this project is a plausible value asserted rather than
checked** — a part number that parses correctly under its manufacturer's scheme, a resistor
value that looks like a jellybean, a count copied from an earlier revision, **a footprint
chosen because its name contained the right characters**. Every one was well-formed and
wrong.

`[AUDIT]` The first version of this document was written to expose exactly that pattern and
still shipped four fresh instances of it, including a build blocker. The lesson is not
"tag your claims" — it is that **naming a thing is not verifying it**, and the tags are only
worth what the checking behind them was worth. Where this document now says `[DS]`, a
datasheet was actually opened.

### 7.1 The inverse failure mode, named 2026-09-02

Once the design stopped moving, the dominant error flipped direction. **The docs now lag
execution rather than overstating it**, and a review that reads only the repo will invent
work that is already done. Three instances surfaced in a single day:

| What the repo said | What was true |
|---|---|
| "Missed-feed alert in HA" was the last unattended-safety gap (item 17) | `automation.reef_tank_feeder_health_watchdog` had been running it since 2026-08-27 |
| `automation.reef_tank_af4_scheduled_feed` "presses the button at each feed time" | It also holds a return-pump interlock, a 15 s pulse confirmation, and a confirmation-gated counter — all load-bearing |
| Firmware "has never been flashed", device "still on GPIO13" (item 11) | Flashed 2026-09-01 18:54, three minutes after the commit that wrote it |

All three were caught by reading the live system — Home Assistant's config and the device's
own reported build timestamp — rather than the documents describing it. **Check reality
before opening an item, and record work at the moment it is done, not at the moment someone
next reads the file.** The provenance tags do not help here: an `[ASSERT]` that has quietly
become true looks identical to one that has not.

---
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

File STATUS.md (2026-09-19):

# STATUS — aF4 PoE Trigger

**Rewritten 2026-09-19.** The only live-status document in this project. Rewrite it;
never append to it. If it passes ~120 lines, something in it belongs in `aF4-MASTER-REFERENCE.md`.

## Phase

**🟢 Commissioning passed, end to end. 6.1 through 6.8, every check, against the real feeder.**
The trigger circuit has now been *measured* rather than argued, and it has driven an actual aF4.
Items 12, 15, 25 and 29 are closed. → §12

**🟢 The reef system is plumbed and running** — confirmed by Kenny, return pump at 142 W. That
retires the longest-standing item in this project and satisfies the scheduled-feed automation's
return-pump interlock. **Go-live is no longer gated on anything but closing the case.** → §12.3

**🟢 The retired ESP32 is erased** — full chip, verified by read-back. Item 30 and the LAN hazard
close together; the bare board is stock silicon now and all it still wants is a label. → §13

**🟢 LIVE. The case is closed, wall-mounted above the sump, and the schedule is on** — Kenny
enabled `input_boolean.reef_af4_schedule_enabled` at **2026-09-18 23:26**, and the board has been
up continuously since 23:18 at `192.168.1.55`. Item 27 is closed. **The first fully automated feed
is 13:30 on 2026-09-19** — nothing has yet run unattended end to end. → §14

| | |
|---|---|
| Board + hat | **Assembled, commissioned and installed.** Case closed and wall-mounted 2026-09-18; both jack noses through the wall, both PoE pipes lit, D5 dark at rest |
| ESP32 | **Online at 192.168.1.55**, adopted in HA, all seven entity IDs intact. Ethernet MAC `00:70:07:7F:48:C3` |
| Firmware | **Complete.** Build `2026-09-18 18:07:52`, config hash `0xd4f82693`. OTA path proven |
| Credentials | ✅ All three rotated and verified |
| 12 V wiring | ✅ **Polarity confirmed by meter** — black tail → TP4 a dead short, red → TP4 open. **Red is +12 V** |
| Enclosure | **Finished and mounted.** Lid on, four screws, light pipes fitted and lit. Item 27 closed |
| HA software | **Complete**, re-verified against the live instance 2026-09-18 |
| Go-live | ✅ **ON since 2026-09-18 23:26.** Both automations armed. Schedule stands at **2/day, 13:30 and 20:30** |

**Nothing is on order and nothing is waiting.**

1. **Watch the 13:30 feed on 2026-09-19** — the first unattended one. It passes when
   `counter.reef_af4_feeds_today` reads 1 and the lockout raises; the counter increments only on a
   *confirmed* pulse, so a stuck 0 is the signal, not a silent success. → §12.4
2. **Nothing else is gated.** Items 26, 24, 20, 22, 14, 18 and the bench leftovers are all
   improvements to a running system.

## What 6.1–6.8 measured

**6.2 = 11.4 V · 6.3 = 10.37 V · 6.4 = 0 V, D5 dark · 6.5 = 10.37 V held 20 s, clean edge ·
6.6 = 310.007 s then 310.013 s · 6.7 link solid · 6.8 the unit fed.** Three of those carry more
than a pass — 6.2 landed on its *predicted* value and would have failed the pre-09-01 band, 6.3
proves R4/R5 by measurement because the LM1117 was not in dropout, and 6.4 is the first hardware
proof of the GPIO32 decision. **§12.2 says what each one settles**; 6.5's clean falling edge also
answers bench item **A6** for free.

## What you may trust

- **Every number above**, and the polarity behind them. This is the first evidence in the project
  that is measurement rather than inference.
- **The build board end to end**: online, adopted, entity IDs intact, OTA path proven, all four
  consumers resolving. Re-checked 09-19: seven entities, no `_2`, online at `192.168.1.55`.
- **That the retired board carries nothing** — erased, and verified at five offsets. → §13
- **That the 23:45 "missed feed(s)" alert on 09-18 was correct and is spent.** The backstop
  counts the day's due slots whole; the schedule went on at 23:26, after both had passed. It
  cannot recur on a day that starts with the toggle already on. → §14.1
- **D3 and D5 are the right way round** — on the build board. Item 25 closed at 6.1 and 6.5.
- **The reef is running.** Return pump 142.245 W against a 10 W threshold.
- **A manual feed leaves no trace in `counter.reef_af4_feeds_today`** — by design; it stayed at 0
  through both of tonight's feeds, and that is not a missing count. **Case work is also silent:**
  both watchdog branches are gated on the schedule toggle. → §12.4
- **The Device Builder YAML is byte-identical** to `firmware/af4-feeder.yaml`, and **the lid
  needs no reprint** — both verified byte-for-byte 2026-09-18.
- **The enclosure at its new geometry** — all checks re-run on the Mac 2026-09-18. 65.2 × 117.0 × 39.9 mm.

## What you may not trust

- ⚠️ **That the aF4's internal schedule resumes when the link cable comes out.** Both vendor
  guides describe only the *connected* state. This project assumed the override direction
  backwards once already — do not assume the reverse. **Verify on the unit.** → item 31
- ⚠️ **Only the build board is proven.** The other four are uninspected (item 26): D3/D5 untested,
  ten J3 joints ungraded, pin-10 excess solder on every board.
- **The 0.72 mm cap clearance is still calculated**, not measured — the stack assembles and the fit
  is good, but no feeler gauge has been on that gap. **Four `PJ_*` values remain uncalipered**, and
  none of them shapes the printed hole or gates a check.
- **Silkscreen reads "10.4V 10s pulse"** — wrong, unfixable on this run. The enclosure scripts run
  only on the Mac (§9.2), and **`gen_pcb.py` / `make_package.py` are un-rerun under KiCad 9.**

## Standing corrections — settled, do not re-raise

- 🚫 **Do not tighten the commissioning bands.** 6.2 measured 11.4 V — the floor. The 09-01
  widening is now validated by a passing board, not just by argument. → §8.1 · §12.6
- 🚫 **A reef sensor reading zero is now suspect, not expected.** The plumbing rule inverted
  2026-09-18. The underlying lesson is unchanged: check what the system is *supposed* to read. → §12.3
- 🚫 **Never compute the Ethernet MAC for a DHCP reservation — read it from the lease.** → §11.1
- 🚫 **On a board swap take HA's "Migrate configuration to new device"** (§11.2), and **an OTA
  password must be punctuation-free** — compare by hash, not by eye (§11.4).
- 🚫 **Never route the 12 V leads across the hat's right-hand edge.** 0.50 mm; a lead there is
  crushed by the lid, invisibly. Down into the void, then along the floor. → §A4
- 🚫 **J1: leave it fitted and dead, plug nothing into it, raise nothing with PCBWay.** → §A4
- 🚫 **A check whose result is fixed by its own inputs is not a check.** → §A4
- 🚫 **Never mount the ESP32 bottom side up**, and **never press the hat fully home on the headers
  outside the case** (§6.3). 🚫 **Item 17 does not exist and never did** (§7.1).
- 🚫 **Wiping an ESP32 is `erase-flash`, not a re-flash** — credentials live in NVS — and the
  verification is a read-back, never the tool's own success line. `read-mac` resets the board it
  is pointed at: identify bench boards with it, never a running one. → §13.1
- ⚠️ **Item numbers are `aF4-MASTER-REFERENCE.md` §8 numbers** — the only numbering.
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

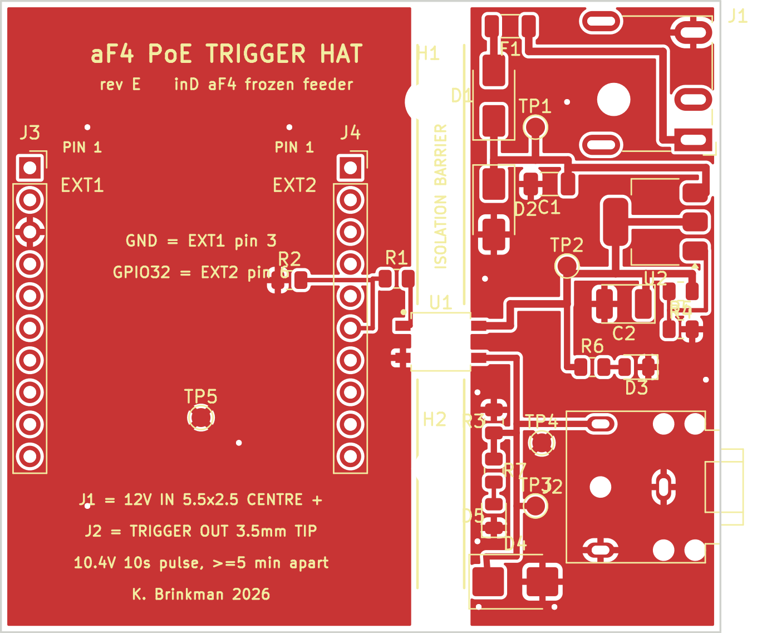
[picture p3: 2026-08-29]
pcb/af4-trigger-hat-rev-E-U1-check.png

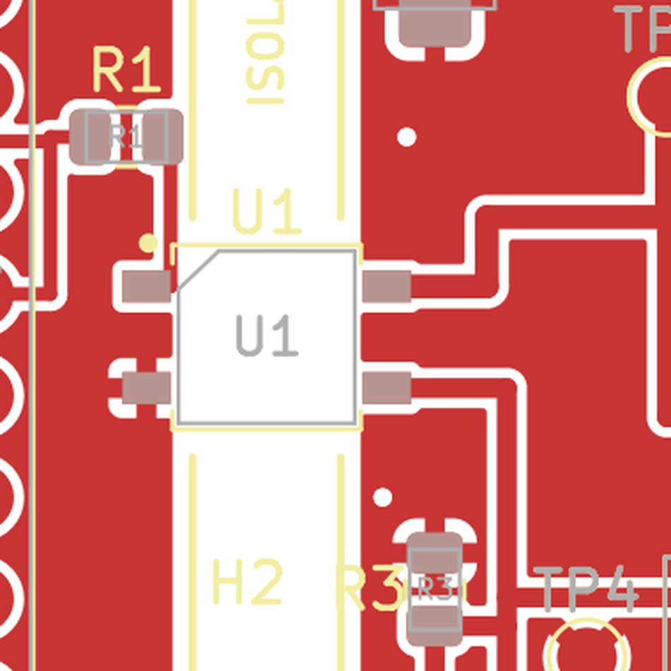
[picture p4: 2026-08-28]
pcb/af4-trigger-hat-rev-D-U1-check.png

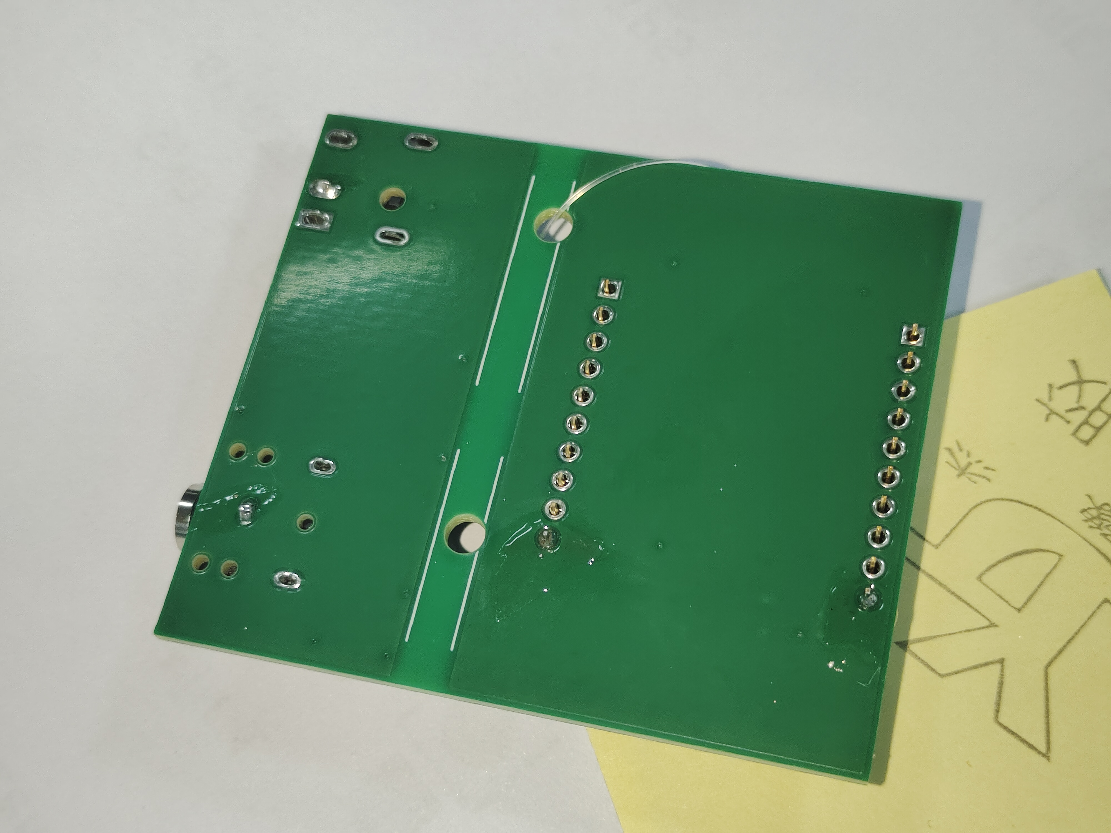
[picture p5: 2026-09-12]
pcb/BOARD REVIEW EQ/rejected-sample-2026-09-11-back.jpg

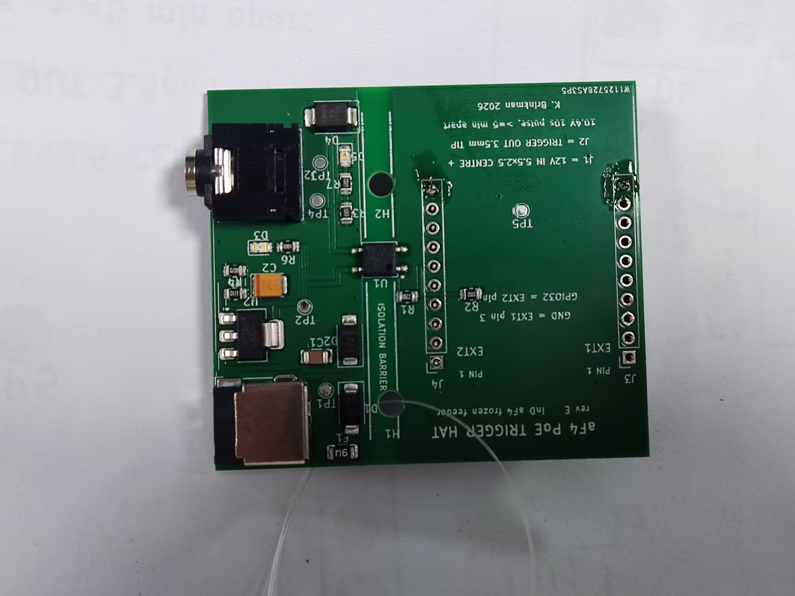
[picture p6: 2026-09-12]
pcb/BOARD REVIEW EQ/rework-2026-09-12-front.jpg

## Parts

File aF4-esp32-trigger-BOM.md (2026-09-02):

# aF4 PoE Trigger — Parts List (rev E)

Goal: a PoE ESP32 running ESPHome pulses 10.4 V (matching the measured OEM level)
onto the aF4's 3.5 mm 0-10 V port (≥9 V for ≥15 s = feed), scheduled from Home
Assistant. Replaces the inD connect dongle.

Rev D moved the whole trigger circuit onto a PCB hat assembled by PCBWay. The
electronics BOM is therefore two lists: **things you buy** (three of them) and
**things that arrive already soldered to the board**.

## What you buy

| Item | Pick | ~Price | Notes |
|---|---|---|---|
| PoE ESP32 board | **Olimex ESP32-POE-ISO** | $28–35 | Get the ISO version. Ships with EXT1/EXT2 unpopulated |
| Trigger hat, assembled | **PCBWay, 5 pcs turn-key** | ~$100–160 for five | Upload `pcb/af4-trigger-hat-rev-E-PCBWay.zip`. See `aF4-pcb-notes.md` |
| 1 × 10 male headers | 2.54 mm, 2 off | pennies | Solder into EXT1/EXT2 **pins up**. Olimex ships these loose; Sullins PRPC010SAAN-RC is equivalent |
| 12 V DC splitter | Barrel Y-splitter, **5.5 × 2.5 mm, centre-positive (confirmed)** | $6 | Taps the feeder's 12 V. Many cheap splitters are 5.5 × 2.1 — buy 2.5 specifically |
| 3.5 mm patch cable | Male–male, mono or stereo, ~0.5 m | $5 | Hat jack → aF4 0-10 V port. Stereo is fine; the aF4's jack shorts ring to sleeve |
| Enclosure | `aF4-trigger-case.stl` + `aF4-trigger-lid.stl` (PETG) | filament | 65.2 × 117.0 × 38.4 mm. See `aF4-enclosure-notes.md` |
| Screws | 4× M3 × 12 self-tapping (lid), 3× M2 × 6–8 (ESP32), 2× M3 × 8–10 (hat) | — | |

**Total: roughly $60–70 for the one-off parts, plus the board order.**

No wire, no heatshrink, no glands, no panel-mount jacks, no polyfuse to splice,
no TVS to bury under heatshrink. All of that is on the board now.

## What's on the board

This is the manufacturing BOM. The machine-readable version PCBWay wants is
`pcb/af4-trigger-hat-BOM.csv`; this table is the human one, with the reasoning.

| Ref | Part | Package | Why this part |
|---|---|---|---|
| U1 | **Panasonic AQY212GS** PhotoMOS, 60 V / 1 A, 0.34 Ω, 1500 Vrms | SOP-4 | Same family and die as the rev C DIP part. Isolation drops 5000 → 1500 Vrms, accepted: both sides are SELV. Pins 3/4 are a symmetric MOSFET pair, no polarity |
| U2 | **TI LM1117MPX-ADJ/NOPB** | SOT-223 | Same die as the rev C TO-220. **The pin-crossing problem is gone** — the footprint puts ADJ where ADJ goes |
| R4 / R5 | 121 Ω / 887 Ω, 1 %, 0805 | 0805 | Vout = 1.25 × (1 + 887/121) = 10.41 V, +53 mV from I_ADJ ≈ **10.47 V**. Fixed by construction. **The rev C sourcing problem vanishes** — 121 Ω 1 % in 0805 is a stocked jellybean, no 18-week lead |
| C1 | 10 µF 50 V X5R | 1206 | Regulator input bulk. X5R, not X7R: Murata's 1206 10 µF 50 V part (GRM31CR61H106KA12L) is X5R; X7R at that C/V needs a 1210 |
| C2 | 10 µF 25 V **tantalum** | EIA-3528 (B) | Must stay tantalum — the LM1117 needs output-cap ESR. 25 V not 16 V: 16 V at a 10.4 V rail is only 65 % derating, and tantalums want 50 %. **Polarised** |
| D1 | **SS14** Schottky, 40 V / 1 A | SMA | **New in rev D.** Reverse-polarity protection in series with the 12 V input — rev C had none at all. Costs 0.3 V of the 1.5 V headroom and turns a polarity mistake into "nothing happens" |
| D2 | **SMAJ13A** TVS, unidirectional | SMA | **New.** Input clamp. 13 V standoff sits above the 12 V rail, so no standing leakage |
| D4 | **SMBJ13CA** TVS, bidirectional | SMB | Was the P6KE15CA spliced behind the plug. Now on-board at the jack. Bidirectional, so no orientation |
| F1 | **1206L010/60WR** PPTC, 0.10 A hold / 0.25 A trip, 60 V | 1206 | Was the MF-R010 spliced into a pigtail. The feeder supply can source 12.5 A; steady draw here is ~19 mA (divider 10.4 + D3 8.3), ~20 mA during a feed |
| R1 | 220 Ω 1 % | 0805 | PhotoMOS LED current, ~9 mA from GPIO32 (6.8 mA worst case at a 3.0 V GPIO and Vf max 1.5 V) — inside Panasonic's recommended 5–30 mA |
| R2 | 10 kΩ 1 % | 0805 | GPIO32 pulldown. **On GPIO32 this is unopposed** — see the GPIO13 note below |
| R3 | 100 kΩ 1 % | 0805 | **New.** Bleeds the trigger line so the port reliably sees 0 V for its 60 s re-arm. 104 µA |
| R6 / D3 | **1.0 kΩ** + green LED | 0805 | **New.** Rail-live indicator, visible through a lid hole. 1.0 kΩ gives 8.2 mA: the APT2012SGC is only 12 mcd typ / 5 mcd min at 20 mA, so at the 10 kΩ first drafted it sat near 0.5 mcd and was invisible |
| R7 / D5 | **6.8 kΩ** + yellow LED | 0805 | **New.** Lights while the trigger is asserted — turns the meter checks into a glance. Only 1.2 mA needed: the APT2012SYCK is 150 mcd at 20 mA, ~12× the green's efficiency, so an equal resistor would badly mismatch them |
| J1 | **Same Sky PJ-079BH**, 5.5 × 2.5 mm, 24 V / 5 A | THT right-angle | **Watch the trap:** PJ-002AH and PJ-102AH are the 2.0–2.1 mm parts. Only the "B" suffix is 2.5 mm centre pin. Same trap as the splitter |
| J2 | **Same Sky SJ1-3523N**, 3.5 mm, 3-conductor | THT right-angle | Tip = signal. Ring is tied to sleeve on the board, which is what a TS plug does anyway |
| J3 / J4 | **Sullins PPTC101LFBN-RC**, 1 × 10 socket, 2.54 mm | THT | Mate EXT1 and EXT2. Their 8.5 mm body height sets the whole vertical stack |
| TP1–TP5 | Test pads: 12 V, 10.4 V, tip, power GND, logic GND | — | Probeable without clipping onto component legs |

Deliberately **not** on the board: a series resistor on the tip. At 10.4 V into a
short it would sit right at the polyfuse's hold current and cook instead of
tripping. The LDO's own current limit plus the polyfuse handle a shorted tip.

## The GPIO13 trap

`af4-feeder.yaml` drives **GPIO32**, not GPIO13. The Olimex board carries a
factory 2.2 kΩ pull-up to 3.3 V on GPIO13 (R35, the I²C SDA pull-up, confirmed in
the Rev N KiCad source). While the ESP32 is in reset, that pull-up feeds the
PhotoMOS LED through R1 with only R2 opposing it — about 0.6–0.7 mA into a part
whose operate current is ~1.1 mA typical, with no guaranteed non-operate floor
below that. `restore_mode: ALWAYS_OFF` cannot help, because the pin is high-Z
before any firmware runs.

GPIO32 touches only the ESP32 module and EXT2 pin 6. No pull-up, no strapping
role, not shared with UEXT. Do not move it back.

## Ordering the board

Upload `pcb/af4-trigger-hat-rev-E-PCBWay.zip`. Order shape: 5 pieces, 2 layers,
1.6 mm, top side populated, full turn-key. 17 SMD placements plus 4 through-hole
parts (28 joints) that they hand-solder. 20 unique part numbers. Full procedure and the fab notes are in
`aF4-pcb-notes.md`.

Distributor part numbers are deliberately blank in the CSV — PCBWay sources by
manufacturer part number. Fill them in only if you want to buy any of it yourself.

## Rev C parts you already own

From the two DigiKey orders (2026-07-11 web ID 373961064 and 2026-07-26 web ID
374640854): the ESP32-POE-ISO carries straight over, and the AQY212GH, MP3-3501,
LM1117T-ADJ, axial resistors, electrolytics, MF-R010 and P6KE15CA become spares.
None of them are used in rev D — the through-hole build they belonged to no
longer exists. Keep the AQY212GH ×2 and the ESP32; the rest is bin stock.

## Is PoE ESP32 right for a 0-10 V application?

Yes, with the same nuance as always: no ESP32 outputs 9–12 V natively. The board
is brains and network; the trigger voltage comes from the feeder's own supply via
the splitter, regulated to 10.4 V on the hat and switched onto the tip by the
PhotoMOS. You do **not** need a 0-10 V DAC — the aF4 treats the port as a
threshold trigger (≥9 V, ≥15 s `[VENDOR] 2026-09-01`), not an analog level.

## Verification before wiring (voltmeter, OEM dongle installed)

Already done and recorded in `aF4-reference.md`: rest voltage 0 V, trigger voltage
10.37 V, link detect mechanical, splitter 5.5 × 2.5 centre-positive.

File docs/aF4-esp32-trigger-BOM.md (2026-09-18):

# aF4 PoE Trigger — Parts List (rev E)

Goal: a PoE ESP32 running ESPHome pulses 10.4 V (matching the measured OEM level)
onto the aF4's 3.5 mm 0-10 V port (≥9 V for ≥15 s = feed), scheduled from Home
Assistant. Replaces the inD connect dongle.

Rev D moved the whole trigger circuit onto a PCB hat assembled by PCBWay. The
electronics BOM is therefore two lists: **things you buy** (three of them) and
**things that arrive already soldered to the board**.

## What you buy

| Item | Pick | ~Price | Notes |
|---|---|---|---|
| PoE ESP32 board | **Olimex ESP32-POE-ISO** | $28–35 | Get the ISO version. Ships with EXT1/EXT2 unpopulated |
| Trigger hat, assembled | **PCBWay, 5 pcs turn-key** | ~$100–160 for five | Upload `pcb/af4-trigger-hat-rev-E-PCBWay.zip`. See `aF4-pcb-notes.md` |
| 1 × 10 male headers | 2.54 mm, 2 off | pennies | Solder into EXT1/EXT2 **pins up**. Olimex ships these loose; Sullins PRPC010SAAN-RC is equivalent |
| 12 V DC splitter | Barrel Y-splitter, **5.5 × 2.5 mm, centre-positive (confirmed)** | $6 | Taps the feeder's 12 V. Many cheap splitters are 5.5 × 2.1 — buy 2.5 specifically |
| 3.5 mm patch cable | Male–male, mono or stereo, ~0.5 m | $5 | Hat jack → aF4 0-10 V port. Stereo is fine; the aF4's jack shorts ring to sleeve |
| Enclosure | `hardware/enclosure/aF4-trigger-case.stl` + `hardware/enclosure/aF4-trigger-lid.stl` (PETG) | filament | 65.2 × 117.0 × 39.9 mm. See `aF4-enclosure-notes.md` |
| Screws | 4× M3 × 12 self-tapping (lid), 3× M2 × 6–8 (ESP32), 2× M3 × 8–10 (hat) | — | |

**Total: roughly $60–70 for the one-off parts, plus the board order.**

No wire, no heatshrink, no glands, no panel-mount jacks, no polyfuse to splice,
no TVS to bury under heatshrink. All of that is on the board now.

## What's on the board

This is the manufacturing BOM. The machine-readable version PCBWay wants is
`pcb/af4-trigger-hat-BOM.csv`; this table is the human one, with the reasoning.

| Ref | Part | Package | Why this part |
|---|---|---|---|
| U1 | **Panasonic AQY212GS** PhotoMOS, 60 V / 1 A, 0.34 Ω, 1500 Vrms | SOP-4 | Same family and die as the rev C DIP part. Isolation drops 5000 → 1500 Vrms, accepted: both sides are SELV. Pins 3/4 are a symmetric MOSFET pair, no polarity |
| U2 | **TI LM1117MPX-ADJ/NOPB** | SOT-223 | Same die as the rev C TO-220. **The pin-crossing problem is gone** — the footprint puts ADJ where ADJ goes |
| R4 / R5 | 121 Ω / 887 Ω, 1 %, 0805 | 0805 | Vout = 1.25 × (1 + 887/121) = 10.41 V, +53 mV from I_ADJ ≈ **10.47 V**. Fixed by construction. **The rev C sourcing problem vanishes** — 121 Ω 1 % in 0805 is a stocked jellybean, no 18-week lead |
| C1 | 10 µF 50 V X5R | 1206 | Regulator input bulk. X5R, not X7R: Murata's 1206 10 µF 50 V part (GRM31CR61H106KA12L) is X5R; X7R at that C/V needs a 1210 |
| C2 | 10 µF 25 V **tantalum** | EIA-3528 (B) | Must stay tantalum — the LM1117 needs output-cap ESR. 25 V not 16 V: 16 V at a 10.4 V rail is only 65 % derating, and tantalums want 50 %. **Polarised** |
| D1 | **SS14** Schottky, 40 V / 1 A | SMA | **New in rev D.** Reverse-polarity protection in series with the 12 V input — rev C had none at all. Costs 0.3 V of the 1.5 V headroom and turns a polarity mistake into "nothing happens" |
| D2 | **SMAJ13A** TVS, unidirectional | SMA | **New.** Input clamp. 13 V standoff sits above the 12 V rail, so no standing leakage |
| D4 | **SMBJ13CA** TVS, bidirectional | SMB | Was the P6KE15CA spliced behind the plug. Now on-board at the jack. Bidirectional, so no orientation |
| F1 | **1206L010/60WR** PPTC, 0.10 A hold / 0.25 A trip, 60 V | 1206 | Was the MF-R010 spliced into a pigtail. The feeder supply can source 12.5 A; steady draw here is ~19 mA (divider 10.4 + D3 8.3), ~20 mA during a feed |
| R1 | 220 Ω 1 % | 0805 | PhotoMOS LED current, ~9 mA from GPIO32 (6.8 mA worst case at a 3.0 V GPIO and Vf max 1.5 V) — inside Panasonic's recommended 5–30 mA |
| R2 | 10 kΩ 1 % | 0805 | GPIO32 pulldown. **On GPIO32 this is unopposed** — see the GPIO13 note below |
| R3 | 100 kΩ 1 % | 0805 | **New.** Bleeds the trigger line so the port reliably sees 0 V for its 60 s re-arm. 104 µA |
| R6 / D3 | **1.0 kΩ** + green LED | 0805 | **New.** Rail-live indicator, visible through a lid hole. 1.0 kΩ gives 8.2 mA: the APT2012SGC is only 12 mcd typ / 5 mcd min at 20 mA, so at the 10 kΩ first drafted it sat near 0.5 mcd and was invisible |
| R7 / D5 | **6.8 kΩ** + yellow LED | 0805 | **New.** Lights while the trigger is asserted — turns the meter checks into a glance. Only 1.2 mA needed: the APT2012SYCK is 150 mcd at 20 mA, ~12× the green's efficiency, so an equal resistor would badly mismatch them |
| J1 | **Same Sky PJ-079BH**, 5.5 × 2.5 mm, 24 V / 5 A | THT right-angle | ⚠️ **Fitted 180° backwards on all five rev E boards and left in place, dead** (§A4). Its pads are still the 12 V entry point, tapped from the hat's underside. **Watch the trap:** PJ-002AH and PJ-102AH are the 2.0–2.1 mm parts. Only the "B" suffix is 2.5 mm centre pin. Same trap as the splitter |
| — | **DALQUIS DC-099**, 5.5 × 2.5 mm, 10 A, threaded panel mount, 150 mm 18 AWG pre-soldered leads | panel, off-board | **Replaces J1 as the 12 V input, 2026-09-18 — already in stock, six of them, and rev C used the same part.** **Red is +12 V, black is −.** Barrel Ø11.50 with a **flat** at 10.50 (the case hole is a D, flat up); nut 3.00 thick, 14.00 across flats. → §A4 |
| — | *Optional:* polarised 2-pin inline connector rated for 18 AWG (JST-VH, **not** XH) | inline | Only if the 150 mm leads do not give enough slack to lift the hat off its headers. Check at the dry fit before buying |
| J2 | **Same Sky SJ1-3523N**, 3.5 mm, 3-conductor | THT right-angle | Tip = signal. Ring is tied to sleeve on the board, which is what a TS plug does anyway |
| J3 / J4 | **Sullins PPTC101LFBN-RC**, 1 × 10 socket, 2.54 mm | THT | Mate EXT1 and EXT2. Their 8.5 mm body height sets the whole vertical stack |
| TP1–TP5 | Test pads: 12 V, 10.4 V, tip, power GND, logic GND | — | Probeable without clipping onto component legs |

Deliberately **not** on the board: a series resistor on the tip. At 10.4 V into a
short it would sit right at the polyfuse's hold current and cook instead of
tripping. The LDO's own current limit plus the polyfuse handle a shorted tip.

## The GPIO13 trap

`firmware/af4-feeder.yaml` drives **GPIO32**, not GPIO13. The Olimex board carries a
factory 2.2 kΩ pull-up to 3.3 V on GPIO13 (R35, the I²C SDA pull-up, confirmed in
the Rev N KiCad source). While the ESP32 is in reset, that pull-up feeds the
PhotoMOS LED through R1 with only R2 opposing it — about 0.6–0.7 mA into a part
whose operate current is ~1.1 mA typical, with no guaranteed non-operate floor
below that. `restore_mode: ALWAYS_OFF` cannot help, because the pin is high-Z
before any firmware runs.

GPIO32 touches only the ESP32 module and EXT2 pin 6. No pull-up, no strapping
role, not shared with UEXT. Do not move it back.

## Ordering the board

Upload `pcb/af4-trigger-hat-rev-E-PCBWay.zip`. Order shape: 5 pieces, 2 layers,
1.6 mm, top side populated, full turn-key. 17 SMD placements plus 4 through-hole
parts (28 joints) that they hand-solder. 20 unique part numbers. Full procedure and the fab notes are in
`aF4-pcb-notes.md`.

Distributor part numbers are deliberately blank in the CSV — PCBWay sources by
manufacturer part number. Fill them in only if you want to buy any of it yourself.

## Rev C parts you already own

From the two DigiKey orders (2026-07-11 web ID 373961064 and 2026-07-26 web ID
374640854): the ESP32-POE-ISO carries straight over, and the AQY212GH, MP3-3501,
LM1117T-ADJ, axial resistors, electrolytics, MF-R010 and P6KE15CA become spares.
None of them are used in rev D — the through-hole build they belonged to no
longer exists. Keep the AQY212GH ×2 and the ESP32; the rest is bin stock.

## Is PoE ESP32 right for a 0-10 V application?

Yes, with the same nuance as always: no ESP32 outputs 9–12 V natively. The board
is brains and network; the trigger voltage comes from the feeder's own supply via
the splitter, regulated to 10.4 V on the hat and switched onto the tip by the
PhotoMOS. You do **not** need a 0-10 V DAC — the aF4 treats the port as a
threshold trigger (≥9 V, ≥15 s `[VENDOR] 2026-09-01`), not an analog level.

## Verification before wiring (voltmeter, OEM dongle installed)

Already done and recorded in `aF4-reference.md`: rest voltage 0 V, trigger voltage
10.37 V, link detect mechanical, splitter 5.5 × 2.5 centre-positive.

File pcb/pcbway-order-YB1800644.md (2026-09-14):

# PCBWay order YB1800644 — aF4 trigger hat rev E

**Status as of 2026-09-14: shipped, DHL (DTP), awaiting delivery.** *Current progress lives
in `STATUS.md`, not here; the shipment record is `aF4-MASTER-REFERENCE.md` §A3.2.* This file is the record of
what was bought, at what price, and what was answered along the way. The design-side story
lives in `docs/aF4-pcb-notes.md`; the submission mechanics and the traps in PCBWay's form live in
`pcbway-new-inquiry-2026-08-29.md`.

| | |
|---|---|
| Order ID | **YB1800644** |
| Placed | 2026-09-02 18:32:27 |
| Sales rep | Ivy Yang, `service33@pcbway.com` |
| Order amount paid | **$169.95** |
| Order status | **Shipped 2026-09-14** (awaiting delivery). Two engineer questions raised and answered |
| Shipped | **2026-09-14**, DHL (DTP), tracking number not posted at the time of reading |

## The two line items

| Item | Product No. | Price | Notes |
|---|---|---|---|
| PCB production | **W1125728AS3P5** | $5.00 × 5 pcs | 57 × 50 mm, 2 layers, 1.6 mm, 1 oz finished copper, **lead-free HASL**, build time 24 h |
| PCB assembly | **T-3P6W1125728A** | $107.96 × 5 | Pads 17, thru-holes 4. Turn-key, top side only |

PCBWay's own page reports the board back to us as **17 pads / 4 thru-hole parts**, which
matches the 17 SMD placements and 4 THT parts (28 joints) the README declares. Their read of
the files agrees with ours.

Uploaded: `af4-trigger-hat-rev-E-GERBERS.zip` on the fabrication item;
`af4-trigger-hat-BOM.xlsx` and `af4-trigger-hat-centroid.xlsx` on the assembly item. The
all-in-one `af4-trigger-hat-rev-E-PCBWay.zip` was **not** used — its fab data is
byte-identical, but the cart splits into two line items with separate file state and the
all-in-one satisfies only one of them.

## The quote, received 2026-09-02

`Quotation T-3P6W1125728A - aF4 trigger hat rev E - quoted BOM 2026-09-02.xls` in this
folder. **All 20 lines priced**, which is what the requote was for.

| | |
|---|---|
| Component cost | $78.96 |
| Assembly cost | $29.00 |
| PCB cost | $5.00 |
| **Quoted total, 5 units** | **$112.96** ($22.59/board) |
| Quoted lead time | **26–28 days** |

The $169.95 paid is that $112.96 plus $56.99 of shipping, tax and handling at checkout.

### Everything the requote was asked for, and what came back

| Asked | Result |
|---|---|
| Assembly cost, which was blank on the rev D sheet | ✅ $29.00 |
| F1 priced — it came back unpriced with a bad MPN (`/60YR`) | ✅ `1206L010/60WR`, $0.409 |
| C1 requoted against the real MPN, not the non-existent X7R | ✅ `GRM31CR61H106KA12L`, $2.417 — **up from $1.459**, see below |
| R6 and R7 added as separate lines | ✅ both present at $0.074, no longer one shared 10 k line |
| 28 hand-soldered joints, not 44 | ✅ order note carries 28; their pad count agrees |
| Total lead time | ✅ 26–28 days |
| No substitutions without confirming | ✅ **none taken.** D5 is `APT2012SYCK` and C1 is the Murata part, both as specified — the TDK alternate was not needed |

### Line pricing, and where the money is

Six lines carry **84 %** of the $78.96:

| Ref | MPN | Unit | × 5 |
|---|---|---|---|
| J1 | PJ-079BH | $2.908 | $14.54 |
| C2 | T491B106K025AT | $2.473 | $12.36 |
| C1 | GRM31CR61H106KA12L | $2.417 | $12.09 |
| J2 | SJ1-3523N | $1.878 | $9.39 |
| U1 | AQY212GS | $1.823 | $9.12 |
| J3, J4 | PPTC101LFBN-RC ×2 | $0.886 | $8.86 |

Movement against the rev D sheet: D1 down ($0.242 → $0.192), J2 down ($2.10 → $1.878),
D5 down ($0.403 → $0.242 on the corrected `SYCK` part), and **C1 up 66 %** ($1.459 →
$2.417). The C1 rise is the one worth recording, because the requote was requested on the
grounds that the corrected part is a stocked commodity — LCSC lists it around $0.23
(`archive/reviews/aF4-prefab-review-2026-08-31.md`). Reviewed and accepted: at $22.59/board for a five-piece
prototype run the absolute number does not justify another round trip. **Noted, not
disputed.**

## Engineering question, 2026-09-02 — raised and answered same day

Flagged on the **PCB fabrication item only** (`W1125728AS3P5`), so it was a CAM question,
not a parts question, and the no-substitutions fence was never tripped.

**Their question:** the 8 plated slots on J1/J2 carry two widths, 0.70 mm and 0.80 mm, but
the fab note says "Route at 0.70 mm as drawn". Confirm they should be machined as drawn.

**Answered 14:05 ET by email to Ivy Yang** — confirm as drawn, no file change. The "0.70 mm"
in the note was the *minimum* across the set, not one value for all eight. Their reading of
the Gerbers was correct.

Verified against `gerbers/af4-trigger-hat.drl` before replying:

| Tool | Ø | Plating | Count | What it is |
|---|---|---|---|---|
| T1 | 0.450 | PTH | 11 | stitching vias |
| T2 | 0.700 | PTH slot (G85) | 5 | J1 shield ×2 (0.70 × 2.20), J2 pads R/S/T ×3 (0.70 × 1.40) |
| T3 | 0.800 | PTH slot (G85) | 3 | J1 pads 1/2/3 (0.80 × 2.00) |
| T4 | 1.000 | PTH | 20 | J3, J4 sockets |
| T5 | 1.200 | **NPTH** | 5 | J2 body pegs |
| T6 | 2.130 | **NPTH** | 1 | J1 locating post |
| T7 | 3.200 | **NPTH** | 2 | M3 mounting holes |

47 drilled features. The reply also **pre-answered the plating split**, because the Excellon
is a single mixed-plating file whose PTH/NPTH boundary lives only in `TA.AperFunction`
comments that CAM can legitimately ignore — the most likely second query. Worth the four
extra lines: PCBWay recalculates lead time from the end of each EQ, so a second one would
have cost another day.

Full text of both the question and the reply: `pcbway-EQ-2026-09-02-reply.md`, with the
wider prepared-answer sheet in `pcbway-EQ-2026-09-02-prepared-answers.md`.

## Shipment, 2026-09-14

| | |
|---|---|
| Status line | This order was Shipped (Awaiting delivery) |
| Carrier | **DHL (DTP)** — understood to be duties-and-taxes-prepaid, covered by the $56.99 taken at checkout. Not verified against PCBWay's terms |
| Shipping time | **2026-09-14** — 12 days after the order was placed, against a quoted 26–28 days, with two engineer questions along the way |
| Tracking number | **Blank** on the page at the time of reading. Deliberately not chased |
| "Estimated Finish Time" | Still read `2026-09-29`. ⚠️ **That field is never recalculated and is not a delivery date.** It is what closed item 21 without answering it |

Full record, including what it changes for the build: `aF4-MASTER-REFERENCE.md` §A3.2.

## What is still owed, on either side

- **PCBWay:** nothing. The boards shipped 2026-09-14 and the EQ thread is closed.
- **Us:** nothing on the board, and nothing to the vendor. The remaining work is the arrival
  inspection (item 26), two male headers into EXT1/EXT2 (item 12), the OTA password rotation
  at that same serial flash (item 16), and commissioning (item 15).

One thing that cannot now be fixed: the silkscreen on these five boards reads
**"10.4V 10s pulse"**. The firmware moved to a 20 s pulse on 2026-09-01, after the Gerbers
shipped. Cosmetic, not worth an EQ, and corrected in `gen_pcb.py` for any future revision.

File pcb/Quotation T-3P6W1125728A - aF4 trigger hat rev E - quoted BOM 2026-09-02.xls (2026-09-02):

PCBWay Bom Quotation, Product No.:T-3P6W1125728A
Item # | *Designator | *Qty | Manufacturer | *Mfg Part # | Description / Value | *Package/Footprint | Mounting Type | Your Instructions / Notes | *Unit Price(5 units) | *Total | *Delivery Time | Customer Reply | PCBWay Update
1 | U1 | 1 | Panasonic | AQY212GS | AQY212GS『 』PhotoMOS solid-state relay, 1 Form A, 60 V / 1 A, 1500 Vrms isolation | SOP-4 | SMD | Isolates ESP32 logic from the feeder supply. Pins 3/4 are a symmetric MOSFET pair - no polarity. | $1.823 | $9.115
2 | U2 | 1 | Texas Instruments | LM1117MPX-ADJ/NOPB | LM1117MPX-ADJ/NOPB『 』LDO regulator, adjustable, 800 mA | SOT-223 | SMD | Tab is VOUT. Set to 10.4 V by R4/R5. | $0.483 | $2.415
3 | D1 | 1 | Vishay | SS14-E3/61T | SS14-E3/61T『 』Schottky rectifier, 40 V / 1 A | SMA (DO-214AC) | SMD | Reverse-polarity protection, in series with the 12 V input. | $0.192 | $0.960
4 | D2 | 1 | Littelfuse | SMAJ13A | SMAJ13A『 』TVS diode, unidirectional, 13 V standoff, 400 W | SMA (DO-214AC) | SMD | Input clamp. Standoff sits above the 12 V rail; cathode to +12 V. | $0.193 | $0.965
5 | D4 | 1 | Littelfuse | SMBJ13CA | SMBJ13CA『 』TVS diode, bidirectional, 13 V standoff, 600 W | SMB (DO-214AA) | SMD | Across the trigger pair at the jack. Bidirectional - no orientation. | $0.242 | $1.210
6 | D3 | 1 | Kingbright | APT2012SGC | APT2012SGC『 』LED, green, 2.2 V typ | 0805 | SMD | 10.4 V rail live indicator. | $0.242 | $1.210
7 | D5 | 1 | Kingbright | APT2012SYCK | APT2012SYCK『 』LED, yellow, 2.0 V typ | 0805 | SMD | Lights while the trigger output is asserted. | $0.242 | $1.210
8 | F1 | 1 | Littelfuse | 1206L010/60WR | 1206L010/60WR『 』PPTC resettable fuse, 0.10 A hold / 0.25 A trip, 60 V | 1206 | SMD | On the 12 V tap. Feeder supply can source 12.5 A. | $0.409 | $2.045
9 | C1 | 1 | Murata | GRM31CR61H106KA12L | GRM31CR61H106KA12L『 』Capacitor, 10 uF, 50 V, X5R | 1206 | SMD | Regulator input bulk. | $2.417 | $12.085
10 | C2 | 1 | Kemet | T491B106K025AT | T491B106K025AT『 』Capacitor, tantalum, 10 uF, 25 V | EIA-3528 (case B) | SMD | Regulator output. Tantalum is required - the LM1117 needs output-cap ESR. POLARISED: + to the 10.4 V rail. | $2.473 | $12.365
11 | R1 | 1 | Yageo | RC0805FR-07220RL | RC0805FR-07220RL『 』Resistor, 220 R, 1%, 1/8 W | 0805 | SMD | PhotoMOS LED current set, ~9 mA from GPIO32. | $0.074 | $0.370
12 | R2 | 1 | Yageo | RC0805FR-0710KL | RC0805FR-0710KL『 』Resistor, 10 k, 1%, 1/8 W | 0805 | SMD | GPIO32 pulldown - holds the PhotoMOS off at boot. | $0.074 | $0.370
13 | R3 | 1 | Yageo | RC0805FR-07100KL | RC0805FR-07100KL『 』Resistor, 100 k, 1%, 1/8 W | 0805 | SMD | Trigger-line bleed, guarantees the 0 V re-arm. | $0.074 | $0.370
14 | R4 | 1 | Yageo | RC0805FR-07121RL | RC0805FR-07121RL『 』Resistor, 121 R, 1%, 1/8 W | 0805 | SMD | LM1117 divider, VOUT to ADJ. | $0.074 | $0.370
15 | R5 | 1 | Yageo | RC0805FR-07887RL | RC0805FR-07887RL『 』Resistor, 887 R, 1%, 1/8 W | 0805 | SMD | LM1117 divider, ADJ to GND. Vout = 1.25*(1+887/121) + Iadj*887 = 10.47 V. | $0.074 | $0.370
16 | R6 | 1 | Yageo | RC0805FR-071KL | RC0805FR-071KL『 』Resistor, 1.0 k, 1%, 1/8 W | 0805 | SMD | D3 green LED series resistor. 8.2 mA - APT2012SGC is only 12 mcd at 20 mA, so it needs the current to be readable through the lid sight hole. | $0.074 | $0.370
17 | R7 | 1 | Yageo | RC0805FR-076K8L | RC0805FR-076K8L『 』Resistor, 6.8 k, 1%, 1/8 W | 0805 | SMD | D5 yellow LED series resistor. 1.2 mA - APT2012SYCK is 150 mcd at 20 mA, so it needs far less current than D3 to match it. | $0.074 | $0.370
18 | J1 | 1 | Same Sky (CUI) | PJ-079BH | PJ-079BH『 』DC power jack, 5.5 x 2.5 mm, 2.5 mm centre pin, 24 V / 5 A | Right-angle THT | THT | MUST be the 2.5 mm centre-pin part. Terminal 3 (switch) is unconnected. | $2.908 | $14.540 | 7-10 Workdays
19 | J2 | 1 | Same Sky (CUI) | SJ1-3523N | SJ1-3523N『 』Audio jack, 3.5 mm, 3-conductor, right angle | THT | THT | Tip = trigger signal. Ring is tied to sleeve on the board. | $1.878 | $9.390 | 7-10 Workdays
20 | J3,J4 | 2 | Sullins | PPTC101LFBN-RC | PPTC101LFBN-RC『 』Socket header, 1x10, 2.54 mm, vertical | THT | THT | Mates the Olimex ESP32-POE-ISO EXT1/EXT2 headers. | $0.886 | $8.860
 |  |  |  |  |  |  |  |  | Component Cost | $78.96
 |  |  |  |  |  |  |  |  | Assembly Cost | $29.00
 |  |  |  |  |  |  |  |  | PCB Cost | $5.00
 |  |  |  |  |  |  |  |  | V0 Member 0% off | $0.00
 |  |  |  |  |  |  |  |  | All Total 5 Units | $112.96
 |  |  |  |  |  |  |  |  | Lead Time | 26-28 days

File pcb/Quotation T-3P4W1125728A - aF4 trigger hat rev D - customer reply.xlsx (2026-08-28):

PCBWay Bom Quotation, Product No.:T-3P4W1125728A
Item # | *Designator | *Qty | Manufacturer | *Mfg Part # | Description / Value | *Package/Footprint | Mounting Type | Your Instructions / Notes | *Unit Price(5 units) | *Total | *Delivery Time | *Actual Purchase Mfg Part # | *PCBWay Note | Customer Reply | PCBWay Update
1 | U1 | 1 | Panasonic | AQY212GS | AQY212GS『 』PhotoMOS solid-state relay, 1 Form A, 60 V / 1 A, 1500 Vrms isolation | SOP-4 | SMD | Isolates ESP32 logic from the feeder supply. Pins 3/4 are a symmetric MOSFET pair - no polarity. | $1.811 | $9.055 |  |  |  | Confirmed - use the part number as listed.
2 | U2 | 1 | Texas Instruments | LM1117MPX-ADJ/NOPB | LM1117MPX-ADJ/NOPB『 』LDO regulator, adjustable, 800 mA | SOT-223 | SMD | Tab is VOUT. Set to 10.4 V by R4/R5. | $0.483 | $2.415 |  |  |  | Confirmed - use the part number as listed.
3 | D1 | 1 | Vishay | SS14-E3/61T | SS14-E3/61T『 』Schottky rectifier, 40 V / 1 A | SMA (DO-214AC) | SMD | Reverse-polarity protection, in series with the 12 V input. | $0.242 | $1.210 |  |  |  | Confirmed - use the part number as listed.
4 | D2 | 1 | Littelfuse | SMAJ13A | SMAJ13A『 』TVS diode, unidirectional, 13 V standoff, 400 W | SMA (DO-214AC) | SMD | Input clamp. Standoff sits above the 12 V rail; cathode to +12 V. | $0.193 | $0.965 |  |  |  | Confirmed - use the part number as listed.
5 | D4 | 1 | Littelfuse | SMBJ13CA | SMBJ13CA『 』TVS diode, bidirectional, 13 V standoff, 600 W | SMB (DO-214AA) | SMD | Across the trigger pair at the jack. Bidirectional - no orientation. | $0.242 | $1.210 |  |  |  | Confirmed - use the part number as listed.
6 | D3 | 1 | Kingbright | APT2012SGC | APT2012SGC『 』LED, green, 2.0 V typ | 0805 | SMD | 10.4 V rail live indicator. | $0.242 | $1.210 |  |  |  | Confirmed - APT2012SGC (green). Please keep this exact part.
7 | D5 | 1 | Kingbright | APT2012SYC | APT2012SYC『 』LED, yellow, 2.0 V typ | 0805 | SMD | Lights while the trigger output is asserted. | $0.403 | $2.015 |  | APT2012SYCK | APT2012SYCK（LED YELLOW CLEAR CHIP SMD），OK？ | APT2012SYCK is ACCEPTED - please purchase APT2012SYCK. Our BOM had a typo: Kingbright does not list an APT2012SYC. Same 0805 footprint, same polarity, yellow 590 nm, 2.0 V typ, water-clear lens - the same lens type as D3.
8 | F1 | 1 | Littelfuse | 1206L010/60YR | 1206L010/60YR『 』PPTC resettable fuse, 0.10 A hold / 0.30 A trip, 60 V | 1206 | SMD | On the 12 V tap. Feeder supply can source 12.5 A. |  |  |  |  | Please provide exact part number or component URL. | Our part number had the wrong packaging suffix. The correct orderable part is Littelfuse 1206L010/60WR - 1206 PPTC, 0.10 A hold / 0.25 A trip, 60 Vdc (Newark 39AH9731). 1206L010/60WR-A (automotive grade, identical electricals) is an acceptable alternate if the /60WR reel is unavailable. Please quote this line - it is currently unpriced.
9 | C1 | 1 | Murata | GRM31CR71H106KA12L | GRM31CR71H106KA12L『 』Capacitor, 10 uF, 50 V, X7R | 1206 | SMD | Regulator input bulk. | $1.459 | $7.295 |  | GRM31CR61H106KA12L |  | GRM31CR61H106KA12L is ACCEPTED - please purchase GRM31CR61H106KA12L. Our part number was wrong: Murata does not make a 10 uF 50 V X7R in 1206. X5R is fine here (indoor use, input bulk cap). PLEASE REQUOTE THIS LINE: USD 1.459/pc was quoted against the non-existent X7R part number; GRM31CR61H106KA12L is a stocked commodity part.
10 | C2 | 1 | Kemet | T491B106K025AT | T491B106K025AT『 』Capacitor, tantalum, 10 uF, 25 V | EIA-3528 (case B) | SMD | Regulator output. Tantalum is required - the LM1117 needs output-cap ESR. POLARISED: + to the 10.4 V rail. | $2.473 | $12.365 |  |  |  | Confirmed - T491B106K025AT. This MUST stay a tantalum: the LM1117 relies on the output capacitor's ESR for loop stability. Do NOT substitute a ceramic (MLCC). POLARISED - the + terminal goes to the 10.4 V rail (pad 1, marked on silkscreen).
11 | R1 | 1 | Yageo | RC0805FR-07220RL | RC0805FR-07220RL『 』Resistor, 220 R, 1%, 1/8 W | 0805 | SMD | PhotoMOS LED current set, ~9 mA from GPIO32. | $0.074 | $0.370 |  |  |  | Confirmed - use the part number as listed.
12 | R2,R6,R7 | 3 | Yageo | RC0805FR-0710KL | RC0805FR-0710KL『 』Resistor, 10 k, 1%, 1/8 W | 0805 | SMD | R2 = GPIO32 pulldown (boot safety); R6/R7 = LED series resistors. | $0.034 | $0.510 |  |  |  | *** BOM CHANGE - PLEASE DO NOT BUY 3x RC0805FR-0710KL FOR THIS LINE. *** This line splits into three parts at three different values: R2 = RC0805FR-0710KL (10 k, 1 off) - unchanged R6 = RC0805FR-071KL (1.0 k, 1 off) - NEW R7 = RC0805FR-076K8L (6.8 k, 1 off) - NEW Same 0805 footprint and same board positions - no gerber or centroid change. A revised BOM (20 lines instead of 18) is attached. Please quote R6 and R7 as two additional lines.
13 | R3 | 1 | Yageo | RC0805FR-07100KL | RC0805FR-07100KL『 』Resistor, 100 k, 1%, 1/8 W | 0805 | SMD | Trigger-line bleed, guarantees the 0 V re-arm. | $0.074 | $0.370 |  |  |  | Confirmed - use the part number as listed.
14 | R4 | 1 | Yageo | RC0805FR-07121RL | RC0805FR-07121RL『 』Resistor, 121 R, 1%, 1/8 W | 0805 | SMD | LM1117 divider, VOUT to ADJ. | $0.074 | $0.370 |  |  |  | Confirmed - use the part number as listed.
15 | R5 | 1 | Yageo | RC0805FR-07887RL | RC0805FR-07887RL『 』Resistor, 887 R, 1%, 1/8 W | 0805 | SMD | LM1117 divider, ADJ to GND. Vout = 1.25*(1+887/121). | $0.074 | $0.370 |  |  |  | Confirmed - use the part number as listed.
16 | J1 | 1 | Same Sky (CUI) | PJ-079BH | PJ-079BH『 』DC power jack, 5.5 x 2.5 mm, 2.5 mm centre pin, 24 V / 5 A | Right-angle THT | THT | MUST be the 2.5 mm centre-pin part. Terminal 3 (switch) is unconnected. | $2.908 | $14.540 | 7-10 Workdays |  |  | Confirmed - PJ-079BH ONLY. This must be the 2.5 mm centre-pin variant. Do NOT substitute PJ-002AH or PJ-102AH: they look identical but are 2.0-2.1 mm and will not accept the power plug.
17 | J2 | 1 | Same Sky (CUI) | SJ1-3523N | SJ1-3523N『 』Audio jack, 3.5 mm, 3-conductor, right angle | THT | THT | Tip = trigger signal. Ring is tied to sleeve on the board. | $2.100 | $10.500 | 7-10 Workdays |  |  | Confirmed - use the part number as listed.
18 | J3,J4 | 2 | Sullins | PPTC101LFBN-RC | PPTC101LFBN-RC『 』Socket header, 1x10, 2.54 mm, vertical | THT | THT | Mates the Olimex ESP32-POE-ISO EXT1/EXT2 headers. | $0.886 | $8.860 |  |  |  | Confirmed - PPTC101LFBN-RC x2. Please seat J3 and J4 flush and square to the board; they mate with a header on a second board and any tilt prevents assembly.
 |  |  |  |  |  |  |  |  | Component Cost | $73.63
 |  |  |  |  |  |  |  |  | Assembly Cost |  |  |  |  | GENERAL REPLY 1/5 - REVISED BOM ATTACHED. The only change from the BOM you quoted is the R2/R6/R7 line splitting into three values (see line 12 above). Everything else is identical. Gerbers, drill and centroid are UNCHANGED - please keep using the files you already have. Attached: 'af4-trigger-hat-BOM.csv' (20 lines).
 |  |  |  |  |  |  |  |  | PCB Cost | $5.00 |  |  |  | GENERAL REPLY 2/5 - PICK AND PLACE: the pick-and-place / centroid file was already included in both uploaded zips as 'af4-trigger-hat-centroid.csv'. It is attached again as 'af4-trigger-hat-pick-and-place.csv'. Origin is the board's LOWER-LEFT corner, Y up, rotations counter-clockwise in degrees. 17 SMD placements, top side only; the 4 THT parts (J1-J4) are not in the file.
 |  |  |  |  |  |  |  |  | V0 Member 0% off | $0.00 |  |  |  | GENERAL REPLY 3/5 - SENSITIVE PARTS: no unusual temperature restrictions; standard lead-free reflow is fine. Please observe normal MSL handling for U1 (AQY212GS PhotoMOS) and C2 (tantalum). No BGA on this board, so X-ray is not required, and we do not need functional test on this 5-unit prototype run.
 |  |  |  |  |  |  |  |  | All Total 5 Units | $78.63 |  |  |  | GENERAL REPLY 4/5 - PLEASE SEND AN UPDATED QUOTATION with (a) the Assembly Cost line filled in, (b) F1 priced, (c) C1 requoted against GRM31CR61H106KA12L, (d) R6 and R7 added, and (e) total lead time. The current 'All Total 5 Units' of USD 78.63 cannot be the final figure.
 |  |  |  |  |  |  |  |  |  |  |  |  |  | GENERAL REPLY 5/5 - CRITICAL: U1 straddles a deliberate copper-free isolation band running the full height of the board. Please do not add copper, vias or stitching in that band - it is the safety barrier between the logic side and the feeder-power side. D1, D2, D3, D5 are polarised; D4 is bidirectional.

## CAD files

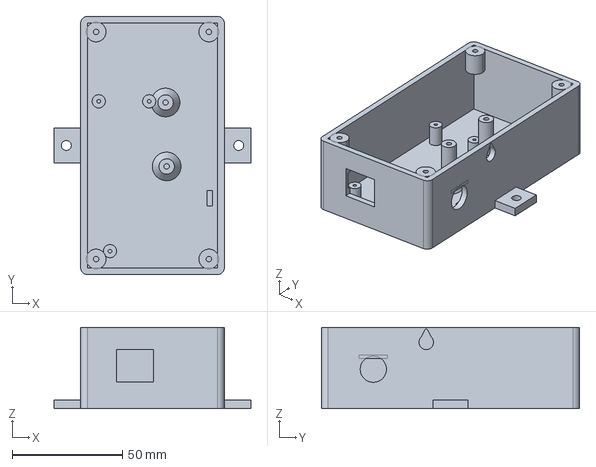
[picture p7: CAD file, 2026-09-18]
hardware/enclosure/aF4-trigger-case.step
89.2 x 117.0 x 36.9 mm

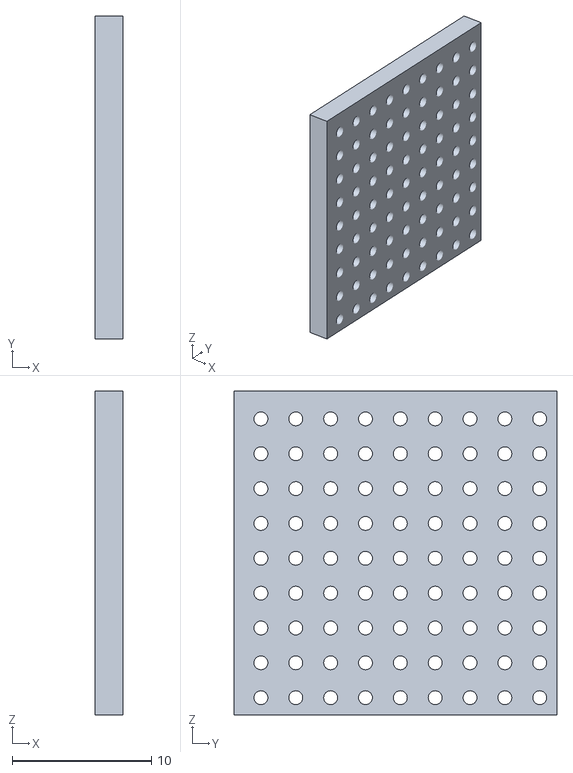
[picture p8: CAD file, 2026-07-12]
protoboard 20x20.stl
2.00 x 23.2 x 23.2

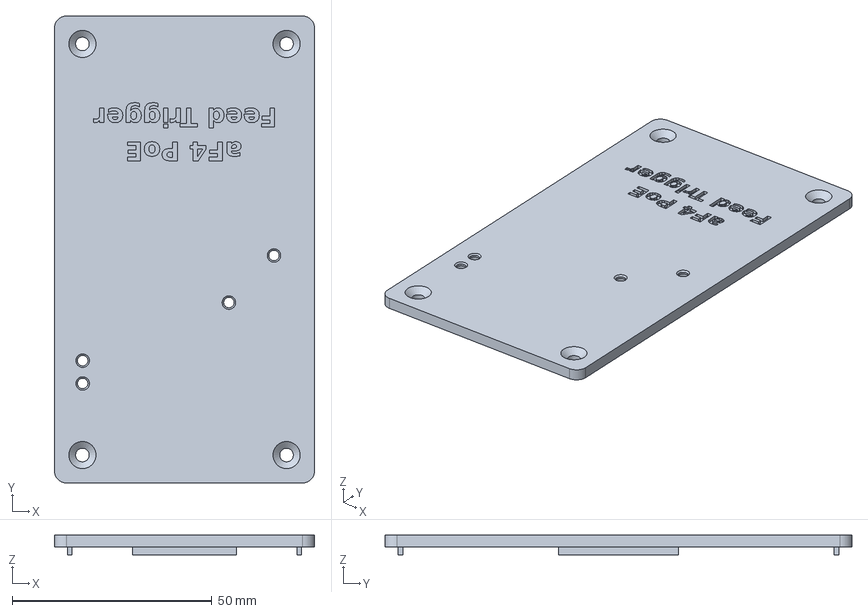
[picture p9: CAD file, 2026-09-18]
hardware/enclosure/af4_lid_inframe.step
65.2 x 117.0 x 5.00 mm

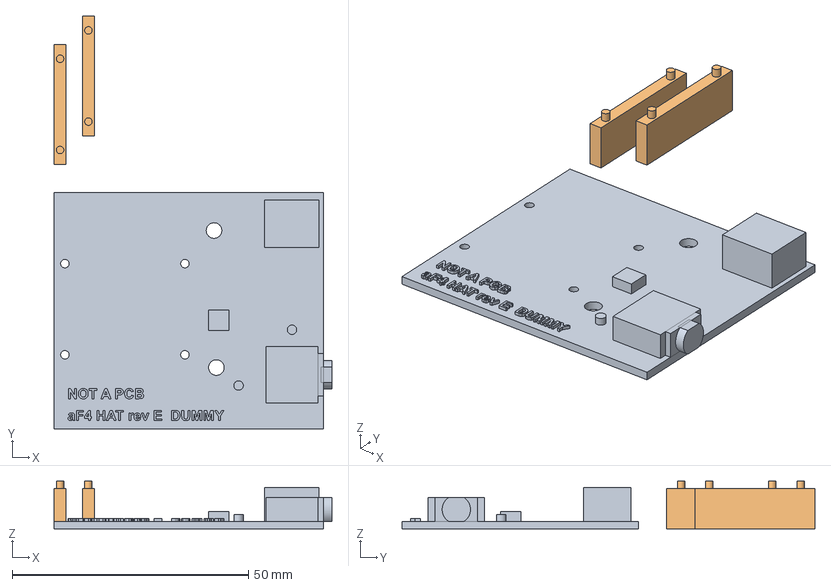
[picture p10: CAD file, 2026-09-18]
hardware/enclosure/aF4-trigger-hat-dummy.step
58.8 x 87.4 x 10.1 mm

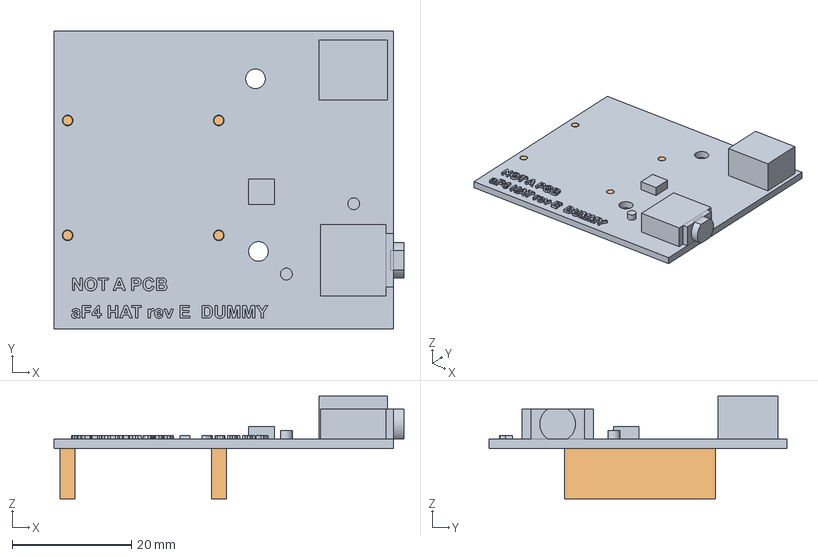
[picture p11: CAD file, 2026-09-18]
hardware/enclosure/af4_hat_dummy_inframe.step
58.8 x 50.0 x 17.3 mm

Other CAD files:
hardware/enclosure/af4_case_inframe.step
hardware/enclosure/aF4-trigger-lid.step
hardware/enclosure/aF4-trigger-case.stl
hardware/enclosure/aF4-trigger-hat-dummy.stl
hardware/enclosure/aF4-trigger-lid.stl

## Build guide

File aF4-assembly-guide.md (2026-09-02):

# aF4 PoE Trigger — Assembly Guide (rev E)

Build sequence for the ESP32-POE-ISO feeder trigger with the rev E PCB hat.
Companion docs: `aF4-esp32-trigger-BOM.md` (parts), `aF4-pcb-notes.md`
(board design and PCBWay ordering), `aF4-enclosure-notes.md` (print details),
`aF4-reference.md` (feeder specs and measured values).

Rev D is a much shorter build than rev C. There is no protoboard to cut, drill,
populate or wire; no resistors to stand on end; no splices to heatshrink; no
regulator pin to sleeve; and nothing to set at the bench. The circuit arrives
assembled and tested. What is left is: print, plug together, flash, meter, enable.

## 0. Parts and tools

Everything from the BOM, plus: a soldering iron (for exactly two headers), a
multimeter, M2 and M3 screwdrivers, and a 3.5 mm mono or stereo patch cable with
a plug on each end.

Not needed any more: 22 AWG wire, heatshrink, the 2.2 mm drill, a hacksaw, a bench
supply, a trimmer tool.

## 1. Print the enclosure

Print `aF4-trigger-case.stl` and `aF4-trigger-lid.stl` in PETG, orientations as
exported, no supports. 3 walls, 15–25 % infill, 0.2 mm layers.

Before going further, test-fit into the +X long wall:

- a 5.5 × 2.5 barrel plug into the counterbored hole,
- a 3.5 mm plug into the smaller hole.

A light chase with a round file is normal on a first print.

Chase the four lid sight holes with a 1/8" drill from the **inside** face only.
Do not open up the Ø2.6 apertures on the outer face — those are the seats the
light pipes land on.

### Light pipes

Four pipes, cut from **3 mm / ⅛" clear acrylic rod**. One 6" rod makes all four
with half of it left over; a 4" rod is also enough.

| Pipe | Over | Cut length | Should stand proud of the lid's INNER face by |
|---|---|---|---|
| ×2 | PWR1 (red), LNK1 (green) — Olimex | **22.7 mm** | 20.6 mm |
| ×2 | D3 (green), D5 (yellow) — hat | **10.1 mm** | 8.0 mm |

The rod occupies 2.10 mm inside the lid (seat at z 25.60 down to the lid
underside at 23.50), which is where that second column comes from. **That is the
check to trust** — seat a pipe dry in the lid and measure the protrusion with
calipers. It verifies the length against the part in your hand, with no board
involved.

**Tolerance is one-sided.** The lengths leave 0.6 mm of air over each LED. Short
is harmless — losing another half-millimetre of gap costs almost nothing in
brightness. Long is not: **a pipe that touches an LED is too long.** When in
doubt cut 0.3 mm short.

**Cutting.** Fine-tooth razor saw in a miter block, cut ~0.5 mm long, then face
to length. Do not use side cutters — acrylic chips and you will crack the rod.
A rotary cut-off disc works but melts a hazed rim you then have to face off
anyway.

**Facing and polishing.** Only the two **ends**. Hold the rod square against
wet-or-dry laid on glass or tile and draw circles: 400 → 800 → 1500 → 2000, then
a plastic polish (Novus 2, PlastX) on a cloth. **Leave the sides alone** — the
rod pipes light by total internal reflection off the acrylic/air sidewall, and
sanding or painting the side is exactly how you dim it. The LED-facing end
matters most; it is the coupling face.

Flame polishing gives a better end but is optional and easy to overdo: one fast
pass with butane, and check with calipers afterwards, because **a bulged end
over 3.5 mm will not pass the bore.**

**Fitting.** Deburr the bore, drop the pipe in from the lid's inside face until
it stops on the aperture step, then a small bead of **clear 5-minute epoxy**
around it on the inside face. Keep the epoxy inside; there is no need for it in
the Ø2.6 well.

- **Do not use cyanoacrylate.** CA crazes acrylic and its vapour will frost the
  polished ends — and anything else in the box.
- **Do not use acrylic solvent cement.** It does not bond PETG and will craze it.
- Neutral-cure silicone is a fine alternative if you would rather have something
  that stays flexible. Hot glue creeps and yellows; don't.

The pipe seats 0.9 mm below the outer face, looking up a shallow Ø2.6 well. That
is deliberate — it protects the end and the well is too shallow to narrow the
view. Cutting the pipes longer to sit flush does not work: a 3 mm rod will not
pass a 2.6 mm aperture.

**Cross-talk** between PWR1 and LNK1 (centres 5.715 mm apart) is not worth
engineering around. Both are steady-state indicators — red on means the 3V3 rail
is up, green on means the link is up — so a little bleed does not change what
either one tells you.

**Check before you close up.** With the splitter tap live and the patch cable in,
you should read red PWR1 and green LNK1 from a metre away, square on.

## 2. Receive and inspect the board

The hat arrives populated. Give it thirty seconds:

- **C2 polarity** — the tantalum's stripe/+ end must face the 10.4 V rail (pad 1,
  marked on the silkscreen).
- **J1 is the 2.5 mm centre-pin jack.** Plug the feeder splitter's tap lead into
  it and confirm it seats with a click, not a wobble. A 2.1 mm part will feel
  loose; if it does, stop — see the note in the BOM.
- **U1 pin 1** dot toward the ESP32 side of the board.
- Nothing bridging the copper-free isolation band running down the middle.

Meter, board unpowered: **J1 centre pin to J2 sleeve should read open** (the
PhotoMOS is off and the LM1117 is unpowered). Between the 12 V test pad and GND
you will read the reverse-polarity diode, not a short.

## 3. Fit the male headers to the ESP32

The Olimex board ships with EXT1 and EXT2 as bare plated holes. Solder a
**1 × 10 male header into each, pins pointing up**, plastic sitting flat on the
board's top face.

Get these square. The hat mates over both at once, and a header leaning even a
couple of degrees will fight the sockets. Tack one end pin, check the header is
flat and perpendicular, then do the remaining nine.

## 4. Flash the ESP32

There is no USB cutout in the case, so flash **before** final assembly if this is
a fresh board. `af4-feeder.yaml` in this folder is the source of truth; paste it
into the ESPHome Device Builder on the Unraid server (port 6052) and install.

> **Do this once before any install.** The YAML no longer carries its credentials
> inline — it reads them with `!secret`, and `!secret` resolves against the
> `secrets.yaml` sitting beside the file being compiled, **not** against this repo.
> Open the Device Builder's Secrets editor and create the four keys listed in this
> folder's `secrets.yaml` (`af4_api_key`, `af4_ota_password`, `af4_web_username`,
> `af4_web_password`). Without them the build fails at compile time with an
> unresolved-secret error, which is the safe way to fail.
>
> **Rotating the OTA password is the one credential change OTA cannot make.**
> ESPHome uses a single value for both compiling the firmware and authenticating
> the upload, so there is no install in which the old password authenticates and
> the new one is written. Changing it in the config simply makes the next upload
> fail against a device that still holds the old one. ESPHome's own documented
> options are an `on_boot` lambda calling `id(my_ota).set_auth_password(...)`
> compiled against the *old* password, or a serial flash. **The API encryption key
> and the web_server password have no such problem** — they are only compiled in,
> never used for the handshake, so they rotate over ordinary OTA.
>
> That is how the 2026-09-02 rotation was done: API key and web password over OTA
> with `af4_ota_password` left at its previous value, and the OTA password itself
> deferred to the next serial flash — the board is on the bench for §3's headers
> anyway.
>
> **Expect Home Assistant to ask.** The API encryption key changed, so the ESPHome
> integration prompts for the new one after the device comes back. Entity IDs and
> history survive — the device name is unchanged. Confirmed working 2026-09-02.

> **If you are re-using the already-flashed board:** the trigger pin changed.
> Rev E drives **GPIO32**, not GPIO13, because of the factory 2.2 kΩ pull-up on
> GPIO13 — see `aF4-pcb-notes.md`. Push the updated YAML over OTA before
> you plug the hat on. The board will do nothing at all until you do.

## 5. Assemble

Order matters — the hat covers two of the ESP32's mounting screws.

1. ESP32-POE-ISO onto its three standoffs, RJ45 into the wall opening, 3 × M2.
2. Hat down onto the two headers. Both jack noses should drop into their wall
   holes as the sockets seat; if they do not line up, the sockets are not fully
   home. Press evenly along the socket rows, not on the jacks.
3. 2 × M3 self-tappers through the hat's mounting holes into the two tall
   standoffs. Snug, not tight — the sockets locate the board, the screws just
   stop it lifting.
4. Leave the lid off for §6.

## 6. Commissioning checks

Ethernet first, feeder power second. All voltages are referenced to the **GND**
test pad on the power side of the board (TP4), not to the ESP32's ground.

| # | Check | Expect |
|---|---|---|
| 6.1 | Splitter tap plugged into J1 | Green LED (D3) lit |
| 6.2 | TP1 (12 V) to TP4 | **11.4–12.0 V** (12 V less the Schottky drop) |
| 6.3 | TP2 (10.4 V) to TP4 | **10.0–10.9 V.** This is the check that matters — it confirms the R4/R5 divider |
| 6.4 | TP3 (tip) to TP4, at rest | 0 V, and the yellow LED (D5) dark |
| 6.5 | Press the Feed button on the ESPHome web page | Yellow LED lights, TP3 reads ~10.4 V for **20 s**, then returns to 0 V |
| 6.6 | Feed Lockout binary sensor | Turns on with the pulse, clears **310 s** later |
| 6.7 | Plug the 3.5 mm patch cable into J2 | **Link LED on the aF4 goes solid** — the port sees the connection |
| 6.8 | Press Feed again | **Link LED flashes green** — the pulse was accepted. Confirms the trigger without waiting to watch food move (newer units; our SN 130063 qualifies) |

If 6.3 reads ~1.4 V, R4 and R5 are swapped. If it reads near 12 V, the divider is
not connected. Either way, stop — do not connect the feeder.

⚠️ **Ranges widened 2026-09-01 on measured evidence.** 6.2 was 11.6–12.2 V and 6.3 was
10.3–10.5 V; **both would have failed a perfectly good board.** The feeder's 12 V rail
measures 11.77 V at its worst under load (`aF4-meter-test-battery.md`, A2), putting TP1
near 11.47 V, and a low-tolerance divider legitimately regulates at 10.08 V.

**If 6.3 reads low, check 6.2 first.** A low-but-passing 6.2 means the LM1117 is simply
in dropout and following its input — the divider is innocent. In dropout the output
lands at ~10.5 V regardless of R4/R5, which is why the widened range is the correct
test rather than a loosened one.

**The ESPHome web page requires a login** — username and password are in `secrets.yaml`,
which is gitignored and not in the repo. Added 2026-09-01 to close an unauthenticated LAN
control path; the credentials were rotated 2026-09-02. Home Assistant is unaffected — it
uses the API, not this page.

**After any reboot inside a feed cycle the device serves a 300 s recovery lockout** and
ignores Feed presses until it clears. If 6.5 does nothing, suspect this before the
hardware — but **do not go looking for it in the log.** The `on_boot` message fires
seconds after boot, while ethernet is still coming up and no log client is attached
yet, and ESPHome does not replay it. Verified 2026-09-01: the line is never observable.

**Read the state instead.** Feed Lockout ON at a low uptime, with nobody having pressed
Feed since the reboot, IS the recovery lockout — `do_feed` state is RAM-only and the
reboot wipes it, so nothing else can hold that sensor on. And check **uptime** first:
a Restart click that silently failed to register looks exactly like a broken lockout.

Only once 6.1–6.6 all pass, connect the 3.5 mm patch cable from J2 to the aF4's
0-10 V port and confirm the link icon lights on the feeder.

## 7. Close up and enable

1. Lid on, 4 × M3 × 12. All four sight holes should land over their LEDs: **D3**
   (green, rail live) and **D5** (yellow, feed) on the hat, **PWR1** (red, 3V3
   rail) and **LNK1** (green, ethernet link) on the Olimex board. With the
   splitter tap live and the patch cable in, all three of D3, PWR1 and LNK1
   should read through the lid without opening anything.
2. In Home Assistant, run one manual feed via `button.af4_feeder_feed` and watch
   the feeder actually cycle.
3. Only then turn on `input_boolean.reef_af4_schedule_enabled`.

## Rev C history

The rev C protoboard build sequence — cutting and drilling the board, standing
the resistors vertically, sleeving the LM1117's crossed pin 1, splicing the
polyfuse into the jack pigtail and the TVS behind the 3.5 mm plug — is preserved
in git history along with `aF4-protoboard-layout.svg` and
`aF4-protoboard-solder-side.svg`. None of it applies to rev D, and the two
protoboard SVGs describe hardware that no longer exists.

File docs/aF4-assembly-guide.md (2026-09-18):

# aF4 PoE Trigger — Assembly Guide (rev E)

Build sequence for the ESP32-POE-ISO feeder trigger with the rev E PCB hat.
Companion docs: `aF4-esp32-trigger-BOM.md` (parts), `aF4-pcb-notes.md`
(board design and PCBWay ordering), `aF4-enclosure-notes.md` (print details),
`aF4-reference.md` (feeder specs and measured values).

Rev E is a much shorter build than rev C. There is no protoboard to cut, drill,
populate or wire; no resistors to stand on end; no splices to heatshrink; no
regulator pin to sleeve; and nothing to set at the bench. The circuit arrives
assembled and tested. What is left is: print, plug together, flash, meter, enable.

## 0. Parts and tools

Everything from the BOM, plus: a soldering iron (for exactly two headers), a
multimeter, M2 and M3 screwdrivers, and a 3.5 mm mono or stereo patch cable with
a plug on each end.

Not needed any more: 22 AWG wire, heatshrink, the 2.2 mm drill, a hacksaw, a bench
supply, a trimmer tool.

## 1. Print the enclosure

Print `hardware/enclosure/aF4-trigger-case.stl` and `hardware/enclosure/aF4-trigger-lid.stl` in PETG, orientations as
exported, no supports. 3 walls, 15–25 % infill, 0.2 mm layers.

Before going further, test-fit into the +X long wall:

- a 5.5 × 2.5 barrel plug into the counterbored hole,
- a 3.5 mm plug into the smaller hole.

A light chase with a round file is normal on a first print.

Chase the four lid sight holes with a 1/8" drill from the **inside** face only.
Do not open up the Ø2.6 apertures on the outer face — those are the seats the
light pipes land on.

### Light pipes

Four pipes, cut from **3 mm / ⅛" clear acrylic rod**. One 6" rod makes all four
with half of it left over; a 4" rod is also enough.

| Pipe | Over | Cut length | Should stand proud of the lid's INNER face by |
|---|---|---|---|
| ×2 | PWR1 (red), LNK1 (green) — Olimex | **24.2 mm** | 22.1 mm |
| ×2 | D3 (green), D5 (yellow) — hat | **10.1 mm** | 8.0 mm |

The rod occupies 2.10 mm inside the lid (seat at z 27.10 down to the lid
underside at 25.00), which is where that second column comes from. **That is the
check to trust** — seat a pipe dry in the lid and measure the protrusion with
calipers. It verifies the length against the part in your hand, with no board
involved.

**Tolerance is one-sided.** The lengths leave 0.6 mm of air over each LED. Short
is harmless — losing another half-millimetre of gap costs almost nothing in
brightness. Long is not: **a pipe that touches an LED is too long.** When in
doubt cut 0.3 mm short.

**Cutting.** Fine-tooth razor saw in a miter block, cut ~0.5 mm long, then face
to length. Do not use side cutters — acrylic chips and you will crack the rod.
A rotary cut-off disc works but melts a hazed rim you then have to face off
anyway.

**Facing and polishing.** Only the two **ends**. Hold the rod square against
wet-or-dry laid on glass or tile and draw circles: 400 → 800 → 1500 → 2000, then
a plastic polish (Novus 2, PlastX) on a cloth. **Leave the sides alone** — the
rod pipes light by total internal reflection off the acrylic/air sidewall, and
sanding or painting the side is exactly how you dim it. The LED-facing end
matters most; it is the coupling face.

Flame polishing gives a better end but is optional and easy to overdo: one fast
pass with butane, and check with calipers afterwards, because **a bulged end
over 3.5 mm will not pass the bore.**

**Fitting.** Deburr the bore, drop the pipe in from the lid's inside face until
it stops on the aperture step, then a small bead of **clear 5-minute epoxy**
around it on the inside face. Keep the epoxy inside; there is no need for it in
the Ø2.6 well.

- **Do not use cyanoacrylate.** CA crazes acrylic and its vapour will frost the
  polished ends — and anything else in the box.
- **Do not use acrylic solvent cement.** It does not bond PETG and will craze it.
- Neutral-cure silicone is a fine alternative if you would rather have something
  that stays flexible. Hot glue creeps and yellows; don't.

The pipe seats 0.9 mm below the outer face, looking up a shallow Ø2.6 well. That
is deliberate — it protects the end and the well is too shallow to narrow the
view. Cutting the pipes longer to sit flush does not work: a 3 mm rod will not
pass a 2.6 mm aperture.

**Cross-talk** between PWR1 and LNK1 (centres 5.715 mm apart) is not worth
engineering around. Both are steady-state indicators — red on means the 3V3 rail
is up, green on means the link is up — so a little bleed does not change what
either one tells you.

**Check before you close up.** With the splitter tap live and the patch cable in,
you should read red PWR1 and green LNK1 from a metre away, square on.

## 2. Receive and inspect the board

The hat arrives populated. Give it thirty seconds:

- **C2 polarity** — the tantalum's stripe/+ end must face the 10.4 V rail (pad 1,
  marked on the silkscreen).
- ⚠️ **J1 is fitted backwards on every rev E board and is DEAD.** Its bore faces
  into the middle of the hat. Do not try to plug anything into it, and do not
  remove it. The 12 V feed comes in through a panel-mount jack in the +X wall,
  wired to J1's pad tails on the hat's **underside**. → §A4
- **U1 pin 1** dot toward the ESP32 side of the board.
- Nothing bridging the copper-free isolation band running down the middle.

Meter, board unpowered: **the +12 V pad tail to J2 sleeve should read open**
(the PhotoMOS is off and the LM1117 is unpowered). Between the 12 V test pad and
GND you will read the reverse-polarity diode, not a short.

🚫 **Route the 12 V leads DOWN, never across the hat's right-hand edge.** There is **0.50 mm**
between the hat edge (x 146.15) and the case's inner wall (146.65) — a lead laid over it is
crushed by the lid and the damage cannot be seen from outside. Drop straight off the pads into
the void beneath the hat, then along the floor to the tie post and the panel jack.

**Identifying the two pad tails on the hat's underside.** J1's three tails sit in
a row at board x 144. The spacing is asymmetric and that is the key — **the wider
gap is on the ground side**: nearest the board's own edge is **GND** (pad 2), then
5.3 mm to the jack's **switch contact** (pad 3, unconnected — leave it), then
3.2 mm to **+12 V** (pad 1), nearest J2. Confirm before soldering: **the GND tail
to TP4 is a dead short.** ⚠️ Do not try the same test on +12 V against TP1 — F1
and D1 sit between them, so a correct board reads a diode drop, not continuity.

## 3. Fit the male headers to the ESP32

The Olimex board ships with EXT1 and EXT2 as bare plated holes. Solder a
**1 × 10 male header into each, pins pointing up**, plastic sitting flat on the
board's top face.

Get these square. The hat mates over both at once, and a header leaning even a
couple of degrees will fight the sockets. Tack one end pin, check the header is
flat and perpendicular, then do the remaining nine.

## 4. Flash the ESP32

There is no USB cutout in the case, so flash **before** final assembly if this is
a fresh board. `firmware/af4-feeder.yaml` in this folder is the source of truth; paste it
into the ESPHome Device Builder on the Unraid server (port 6052) and install.

> **Do this once before any install.** The YAML no longer carries its credentials
> inline — it reads them with `!secret`, and `!secret` resolves against the
> `firmware/secrets.yaml` sitting beside the file being compiled, **not** against this repo.
> Open the Device Builder's Secrets editor and create the four keys listed in this
> folder's `firmware/secrets.yaml` (`af4_api_key`, `af4_ota_password`, `af4_web_username`,
> `af4_web_password`). Without them the build fails at compile time with an
> unresolved-secret error, which is the safe way to fail.
>
> **Rotating the OTA password is the one credential change OTA cannot make.**
> ESPHome uses a single value for both compiling the firmware and authenticating
> the upload, so there is no install in which the old password authenticates and
> the new one is written. Changing it in the config simply makes the next upload
> fail against a device that still holds the old one. ESPHome's own documented
> options are an `on_boot` lambda calling `id(my_ota).set_auth_password(...)`
> compiled against the *old* password, or a serial flash. **The API encryption key
> and the web_server password have no such problem** — they are only compiled in,
> never used for the handshake, so they rotate over ordinary OTA.
>
> That is how the 2026-09-02 rotation was done: API key and web password over OTA
> with `af4_ota_password` left at its previous value, and the OTA password itself
> deferred to the next serial flash — the board is on the bench for §3's headers
> anyway.
>
> **Expect Home Assistant to ask.** The API encryption key changed, so the ESPHome
> integration prompts for the new one after the device comes back. Entity IDs and
> history survive — the device name is unchanged. Confirmed working 2026-09-02.

> **If you are re-using the already-flashed board:** the trigger pin changed.
> Rev E drives **GPIO32**, not GPIO13, because of the factory 2.2 kΩ pull-up on
> GPIO13 — see `aF4-pcb-notes.md`. Push the updated YAML over OTA before
> you plug the hat on. The board will do nothing at all until you do.

## 5. Assemble

Order matters — the hat covers two of the ESP32's mounting screws.

1. ESP32-POE-ISO onto its three standoffs, RJ45 into the wall opening, 3 × M2.
2. Hat down onto the two headers until it **rests on its two tall standoffs**. Both
   jack noses should drop into their wall holes on the way. The sockets stop about
   1.5 mm above the header plastic — that gap is deliberate, it lifts the hat clear of
   the capacitor beside the Olimex power module. Press evenly along the socket rows,
   not on the jacks. ⚠️ **Never press the hat fully home on the headers with the board
   out of the case** — it would bottom on the plastic and land on that capacitor.
3. 2 × M3 self-tappers through the hat's mounting holes into the two tall
   standoffs. Snug, not tight — the standoffs set the height and the sockets locate
   the board sideways.
4. Leave the lid off for §6.

## 6. Commissioning checks

Ethernet first, feeder power second. All voltages are referenced to the **GND**
test pad on the power side of the board (TP4), not to the ESP32's ground.

| # | Check | Expect |
|---|---|---|
| 6.1 | Splitter tap plugged into the **12 V panel jack** in the +X wall (J1 is dead, §A4) | Green LED (D3) lit |
| 6.2 | TP1 (12 V) to TP4 | **11.4–12.0 V** (12 V less the Schottky drop) |
| 6.3 | TP2 (10.4 V) to TP4 | **10.0–10.9 V.** This is the check that matters — it confirms the R4/R5 divider |
| 6.4 | TP3 (tip) to TP4, at rest | 0 V, and the yellow LED (D5) dark |
| 6.5 | Press the Feed button on the ESPHome web page | Yellow LED lights, TP3 reads ~10.4 V for **20 s**, then returns to 0 V |
| 6.6 | Feed Lockout binary sensor | Turns on with the pulse, clears **310 s** later |
| 6.7 | Plug the 3.5 mm patch cable into J2 | **Link LED on the aF4 goes solid** — the port sees the connection |
| 6.8 | Press Feed again | **Link LED flashes green** — the pulse was accepted. Confirms the trigger without waiting to watch food move (newer units; our SN 130063 qualifies) |

If 6.3 reads ~1.4 V, R4 and R5 are swapped. If it reads near 12 V, the divider is
not connected. Either way, stop — do not connect the feeder.

⚠️ **Ranges widened 2026-09-01 on measured evidence.** 6.2 was 11.6–12.2 V and 6.3 was
10.3–10.5 V; **both would have failed a perfectly good board.** The feeder's 12 V rail
measures 11.77 V at its worst under load (`aF4-meter-test-battery.md`, A2), putting TP1
near 11.47 V, and a low-tolerance divider legitimately regulates at 10.08 V.

**If 6.3 reads low, check 6.2 first.** A low-but-passing 6.2 means the LM1117 is simply
in dropout and following its input — the divider is innocent. In dropout the output
lands at ~10.5 V regardless of R4/R5, which is why the widened range is the correct
test rather than a loosened one.

**The ESPHome web page requires a login** — username and password are in `firmware/secrets.yaml`,
which is gitignored and not in the repo. Added 2026-09-01 to close an unauthenticated LAN
control path; the credentials were rotated 2026-09-02. Home Assistant is unaffected — it
uses the API, not this page.

**After any reboot inside a feed cycle the device serves a 300 s recovery lockout** and
ignores Feed presses until it clears. If 6.5 does nothing, suspect this before the
hardware — but **do not go looking for it in the log.** The `on_boot` message fires
seconds after boot, while ethernet is still coming up and no log client is attached
yet, and ESPHome does not replay it. Verified 2026-09-01: the line is never observable.

**Read the state instead.** Feed Lockout ON at a low uptime, with nobody having pressed
Feed since the reboot, IS the recovery lockout — `do_feed` state is RAM-only and the
reboot wipes it, so nothing else can hold that sensor on. And check **uptime** first:
a Restart click that silently failed to register looks exactly like a broken lockout.

Only once 6.1–6.6 all pass, connect the 3.5 mm patch cable from J2 to the aF4's
0-10 V port and confirm the link icon lights on the feeder.

## 7. Close up and enable

1. Lid on, 4 × M3 × 12. All four sight holes should land over their LEDs: **D3**
   (green, rail live) and **D5** (yellow, feed) on the hat, **PWR1** (red, 3V3
   rail) and **LNK1** (green, ethernet link) on the Olimex board. With the
   splitter tap live and the patch cable in, all three of D3, PWR1 and LNK1
   should read through the lid without opening anything.
2. In Home Assistant, run one manual feed via `button.af4_feeder_feed` and watch
   the feeder actually cycle.
3. Only then turn on `input_boolean.reef_af4_schedule_enabled`.

## Rev C history

The rev C protoboard build sequence — cutting and drilling the board, standing
the resistors vertically, sleeving the LM1117's crossed pin 1, splicing the
polyfuse into the jack pigtail and the TVS behind the 3.5 mm plug — is preserved
in git history along with `archive/rev-c-protoboard/aF4-protoboard-layout.svg` and
`archive/rev-c-protoboard/aF4-protoboard-solder-side.svg`. None of it applies to rev E, and the two
protoboard SVGs describe hardware that no longer exists.

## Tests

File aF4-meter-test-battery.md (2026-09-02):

# aF4 meter test battery

Bench procedure for closing the measurement-dependent open items.
Started **2026-09-01**. **None of it requires opening the aF4**, so the warranty
stays intact.

## Status at a glance

| Test | What it settles | State |
|---|---|---|
| **A1** brick open-circuit | Open item 7, TVS standoff | ✅ **DONE — PASS**, headroom amber |
| **A2** loaded rail at splitter tap | LM1117 dropout headroom | ✅ **DONE — ACCEPT, no board change.** Forces the check-6.3 widening |
| **A3** port pinout | Port impedance | 🟨 ring question **closed by A7**; both-polarity check outstanding |
| **A4** dongle voltage open vs loaded | The 10.4 V target | 🟨 **V_open = 10.35→10.37 V**; V_loaded still to do |
| **A5** port input current | Open item 6 | 🟨 inferred (~0.95 mA), needs powered confirmation |
| **A6** port decay time | R3 bleed value | ⬜ not run |
| **A7** OEM plug pinout | J2 ring-to-sleeve tie | ✅ **DONE** — tip + sleeve, ring floats. **Keep the tie, no board change** |
| **A8** dongle pulse shape | Whether inD's 10 s is dongle logic | ✅ **DONE — pass-through, no fixed pulse.** B1's premise stands |
| **B1** hold-time sweep | 6 s vs 15 s | ⬜ confirmatory only |
| **B2** re-arm interval | R2 | ⬜ low value, confounded |
| **B3** held-high = one feed | Audit finding B5 | ⬜ high value |
| **C** commissioning | Go-live gate | ⬜ needs the built hat |

**Suggested run order:** ~~A7~~ → **A2** → A4 and A8 together → A5 confirm → A6 →
B3 → B1 → B2.

---

## Why the order matters

The rev E order is submitted to PCBWay but **not paid and not fabbed**. This is
the last cheap window to act on a measurement.

- **Group A can change the board.** Run before paying.
- **Group B only changes firmware.** Any time.
- **Group C needs the built hat.** It is the commissioning pass.

---

## What is already settled

**From measurement, 2026-09-01:**

- **Brick open-circuit 12.13 V, stable, centre-positive.** Well under the SMAJ13A's
  13 V standoff → no idle TVS conduction. **Open item 7 closed.**
- **~11 kΩ tip-to-sleeve** on the port (unpowered, through a TS plug) → about
  **0.95 mA at 10.4 V**. Against an 18.7 mA quiescent budget and F1's 100 mA hold
  that is negligible. **Open item 6 effectively answered**, pending A5.
- **The OEM dongle's plug is TRS but carries only two wires** — one conductor is
  unused. See the teardown section; this is board-affecting.

**From inD's own documentation** (full account in `aF4-vendor-docs-notes.md`):

- **5-minute minimum spacing** between feeds — vendor-stated, so our 300 s cycle
  is now sourced rather than derived.
- **A held-high line yields exactly one feed** — the Apex guide's worked example
  holds ON for 14 minutes and produces one feed. Independent corroboration of
  audit finding B5.
- **`R1` — inD publishes THREE hold times**: 6 s (Neptune Systems page, audit-verified
  2026-08-28), 10 s (inD Connect), 15 s (Hydros). The 6 s is genuine, just the most
  permissive. Design to 15 s; the 10 s pulse fails it. **20 s clears all three.**
- **Connecting the link port overrides the aF4's internal 24-hour schedule**, so an
  offline ESP32 means the fish are silently never fed.
- 12 V / 12.5 A brick confirms `R6`. Driving the port is documented, supported use.

---

## Decisions pending before payment

Three things could still change the board. Two are answerable at the bench in
under an hour.

1. ~~**A2's result.**~~ **CLOSED 2026-09-01 — ACCEPT, no board change.** Loaded
   minimum 11.77 V. Sits on the dropout boundary, but the output lands at ~10.47 V
   either way and threshold margin is ~1.5 V. **Forces the check-6.3 widening.**
2. ~~**J2's ring — tie or float.**~~ **CLOSED 2026-09-01 by A7 — keep the tie, no
   board change.** See A7 for the reasoning.
3. **R5's power rating.** It sits at ~96 mW against an 0805's 125 mW — **77 %**.
   A 0.25 W part is a drop-in. Raising the divider impedance is **not** available:
   it is the minimum-load ballast. Window closes at assembly.

---

## Prerequisites

| Item | Note |
|---|---|
| DMM | Any DC voltmeter. **Min/Max is NOT needed** — the load that matters is sustained. Film the meter during a feed if you want fine detail |
| **TRS** 3.5 mm breakout | Three separate pigtails, or a TRS screw-terminal adapter (~$5). A **TS breakout cannot do A3** — see the trap below |
| 100 Ω and 1 kΩ resistors | Bin stock, ¼ W fine |
| inD Connect dongle + eWeLink app | The known-good OEM signal source |
| Phone stopwatch | |
| Cup or container, ≥12 oz | |
| Sink or catch basin | |

**Never measure port current with the DMM in series in amps mode.** Burden voltage
is unpredictable, and a meter left in amps mode is the classic way to blow a fuse
or worse. A5 uses a series resistor — safer, and it yields input impedance free.

### Unit identity — recorded 2026-09-01

| Field | Value |
|---|---|
| Part number | **10102101** |
| Serial number | **130063** |

**The serial falls outside every range inD documents.** Their fan guide covers
`20XXX` / `60XXX` (full shutdown on over-temperature) and `100XXX` (standby with
continuous beeping, cooling continues, manual restart). A **130XXX is newer than
all of them**, so it most likely behaves like `100XXX` or newer — inference, not
documentation. Neither behaviour self-clears, and neither signals Home Assistant,
which is part of the case for dispense confirmation — a fault is invisible to HA even with the missed-feed watchdog running, because the pulse still succeeds. Master-reference item 20.

**Consequence worth having:** the link LED's flash-green-on-feed-signal is
documented as "newer units only". This unit is newer than any published range, so
**commissioning step 6.8 should be available.**

The 2024 solenoid manufacturing defect inD references should not apply to a unit
this recent.

---

## Setup S1 — the safe feed configuration

Used by every test that triggers a real feed. This is inD's own pre-use-rinse
arrangement, so it is a documented-safe way to run the unit.

1. aF4 upright on a counter near a sink. **Never on its side.**
2. Reservoir at least half full of plain water. **No food** — it only makes cycles
   messy and results harder to read.
3. Black intake tube fully submerged in a cup with ≥12 oz of water.
4. Grey output tube into the sink or a catch container. **Not the tank.**
5. Power on with a firm 3-second press. Solid green LED.
6. Feed quantity set to **1 LED (5 mL)** — shortest cycle, least water.

**Every triggered feed is auto-followed by a self-clean, so budget 5 minutes per
trial.** A five-point sweep is a 25-minute test. Do not rush it by re-triggering
early — you will only be measuring the spacing lockout. Never run the pump dry.

---

# Group A — board-affecting

## A1 — brick open-circuit voltage ✅ DONE

**Result: 12.13 V, stable, centre-positive. Open item 7 closed.**

TVS verdict **PASS** — well under the SMAJ13A's 13 V standoff, so no idle
conduction and no part change. Headroom verdict **AMBER** — this is the bottom of
the healthy band, and it is the *open-circuit* figure. Load only lowers it, which
is what makes A2 the priority.

*Method, for reference:* brick unplugged from the aF4, still on mains, DMM on DC
volts. **Black probe on the outer metal barrel, red probe INTO the centre hole.**

> On a male DC barrel plug the positive contact is a **hollow tube, not a
> protruding pin** — the pin lives in the female jack on the device. "5.5 × 2.5"
> means a 5.5 mm outer barrel and a **2.5 mm hole**, and that hole is the positive
> contact. A needle probe drops in. If it will not sit steady, push a short length
> of stripped solid-core wire or a male header pin into the hole and probe that.

> **The brick is rated 12.5 A.** Red probe slipping onto the outer barrel is a dead
> short across ~150 W. A 0 V reading almost always means lost contact, not a dead
> supply.

## A2 — loaded rail voltage at the splitter tap ⬜ THE PRIORITY

This is the actual input to the hat's LM1117, minus the SS14's ~0.3 V. The master
reference already establishes how tight it is:

| Brick | LDO input | Headroom to 10.47 V |
|---|---|---|
| 12.2 V | 11.90 V | 1.43 V ✓ |
| 12.0 V | 11.70 V | 1.23 V ✓, but a worst-case divider is **in dropout** |
| 11.6 V | 11.30 V | **in dropout** |

The aF4 is a 12.5 A load running a TEC, pump, solenoid and fan off this brick.
Sag is entirely plausible and has never been measured. **A1's 12.13 V starting
point means there is less headroom in hand than the design assumed.**

### Run it on the FIRST power-on — that is the worst case

The feeder has never been powered. **The first cool-down from room temperature is
the heaviest sustained load the brick will ever see**, because the TEC runs flat
out while it is far from setpoint. A2 taken now is genuinely worst case.

inD also requires a **pre-use rinse** before first use, so the two fold into one
session. This procedure is their rinse with the measurement layered on top.

#### Step 0 — before plugging anything in

- **The tank mount and cleaning tablet ship INSIDE the reservoir.** Remove both
  before adding water or the tablet dissolves.
- Uncoil the tubing (factory-fitted, no assembly). Check contents against the
  packing list; contact support rather than installing anything damaged.
- **Write down the serial number** from the underside sticker while the unit is
  still easy to tip.

#### Step 1 — meter hookup, using the dongle as a breakout

Better than holding probes in a barrel connector, and it frees your hands.

1. OEM splitter **female** end → power supply.
2. Splitter **short male** → inD Connect dongle.
3. Splitter **long male** → aF4.
4. **Leave the dongle's 3.5 mm plug OUT of the aF4** — it must not assert during
   the test. The dongle is only a powered breakout here.
5. **Alligator-clip the DMM across J1's two solder lugs on the dongle board** —
   the raw barrel input, ahead of any protection. Clips, not handheld probes: this
   needs to run unattended for half an hour.
6. DC volts. **Min/Max is not required** — the TEC is a *sustained* load, so a
   plain meter reads it correctly, and pump/solenoid events last seconds, not
   milliseconds. For fine detail during a feed, **prop a phone and film the meter**,
   then scrub back: ~30 readings/sec, better than most Min/Max modes.

7. **Sanity-check the rig before trusting it.** With mains connected and the aF4
   still switched off, the meter should read **≈ 12.1 V**, matching A1. Anything
   wildly different means the clips are wrong — stop and re-check. Record it as
   the **baseline**.

Cross-check once against **TP_12V**. Same reading → fine. TP_12V a few hundred mV
lower → D1 is in series and TP_12V is not the number you want; **trust the J1 lugs**.

#### Step 2 — fill, per inD's rinse procedure

- Reservoir at least half full of **warm** water.
- Long black intake tube **fully submerged** in a glass or bowl with ≥ 12 oz.
- Grey output tube into the sink or a catch container. Unit upright.
- **Temperature setting 3 or higher if convenient**, but do not fuss: nothing
  freezes in half an hour from room temperature. The freezing risk applies only to
  running for *hours* at setting 1 with plain freshwater. Load is unaffected either
  way — during pull-down from ambient the TEC draws full power whatever the setpoint.
- Power on with a firm **3-second** press. Wait for solid green.

#### Step 3 — cool-down, 20–30 min (sustained maximum load)

Leave it running with the meter recording. Note the reading a minute or two in,
then walk away and come back for the captured minimum.

> **Watch the temperature LEDs on this first run.** All five flashing together is
> an over-temperature fault, and *when* it starts is the diagnosis: **immediately**
> = fan failure; **within 3 h** = bad probe; **after 3 h** = genuinely hot. This
> unit's serial is outside every documented range, so **record whether it beeps and
> holds in standby or shuts down outright** — that is a new data point and it tells
> you which recovery to expect. It will not self-clear either way.

#### Step 4 — rinse feeds (transient load on top of the TEC)

Still recording, run inD's rinse: press **Feed Now**, let the full cycle *including
auto-clean* finish, and repeat **two more times** — about 5 minutes each.

If nothing dispenses, run one **Auto-Clean** and retry Feed Now before worrying.

#### Step 5 — shut down

Power off and drain the reservoir.

**Completed 2026-09-01.** inD's pre-use rinse requirement is satisfied; the unit
has been flushed three times and is ready for first real use.

#### Record

The idle reading, and the **minimum across the whole session**.

| Minimum | Verdict |
|---|---|
| **≥ 12.2 V** | PASS — the headroom assumption holds |
| 12.0 – 12.2 V | Marginal. A worst-case divider rides dropout. Functional, unregulated |
| 11.6 – 12.0 V | **CONCERN** — nominal parts enter dropout during feeds |
| **< 11.6 V** | **Board-affecting.** Shared-rail approach needs rethinking — separate supply for the hat, or a different regulator topology |

Dropout is **not a safety failure**: the LM1117 degrades to roughly V_IN − 1 V,
still inside the 9–11 V window, so feeds still trigger. What is lost is regulation
and ripple rejection. But if this lands under 12.0 V, say so **before paying** —
far cheaper to change now than after assembly.

Short sub-100 ms transients would need a scope; do not chase them — the hat's
10 µF input cap rides through those anyway. Sustained sag is the whole question.

**Report four numbers:** baseline (aF4 off), idle with the TEC running, lowest
during cool-down, lowest during a feed.

**Given A1's 12.13 V unloaded, anything but a small sag lands in the marginal band
immediately.** That is precisely what is worth knowing before paying.

> **Two cautions.** The dongle is an open board carrying 12 V — keep it off
> anything conductive and never bridge J1's lugs, which is a dead short across a
> 12.5 A supply. And do not short the boost output; live 10 V rail with an
> inductor behind it.

### A2 VERDICT, 2026-09-01 — ACCEPT. No board change.

| Reading | Value |
|---|---|
| Baseline, aF4 off | 12.13 V |
| Idle, TEC running | 11.84 → 11.86 V (sag 0.29 V, stable) |
| **Minimum during feed** | **11.77 V**, recovering immediately |
| Repeatability | **Floor held at 11.77 V across all three rinse cycles** |

The feed adds only **0.09 V** over the TEC load — pump and solenoid are minor
next to the TEC, so there is no transient risk hiding behind the steady figure.
**Confirmed over three complete feed + auto-clean cycles**: same floor each time,
immediate recovery, no drift or droop as the run went on — which is where a
genuinely marginal supply would have shown itself.
Total sag from baseline 0.36 V. Measured under the heaviest conditions the unit
will ever see: first pull-down from ambient, TEC flat out, feed stacked on top.

**Worst case:** 11.77 V − 0.3 V (SS14) = **11.47 V at the LDO**, giving exactly
**1.00 V** headroom against ~1 V of dropout — precisely on the boundary.

**Why that is a non-event:**

1. **In dropout the output lands where regulation would have put it.**
   11.47 − 1.0 ≈ **10.47 V**, versus a 10.47 V regulated target. The two answers
   converge at this input voltage.
2. **Threshold margin is ~1.5 V.** For the output to fall under 9 V the brick
   would have to sag to ~10.3 V. Nothing in a feed cycle approaches that.
3. **Dropout makes the divider tolerance BETTER, not worse.** With the pass device
   saturated, V_OUT follows V_IN regardless of what R4/R5 ask for — so the
   worst-case-high stack the audit flagged simply sits at ~10.47 V instead of
   10.88 V. Real spread becomes ~10.08–10.5 V, **tighter than designed**.
4. **~1 V dropout is the audit's conservative figure.** At 20 mA the true value is
   likely lower, in which case it regulates normally and none of this applies.
5. **What is lost — regulation and PSRR — is not needed.** The port is a threshold
   input with a ≥10 s hold, not an analog input. It cannot tell the difference.

**Considered and rejected:** retargeting the divider lower to guarantee regulation.
That trades a known-good 10.5 V for a lower voltage with less threshold margin, to
fix something that is not causing harm.

### ⚠️ This makes the check-6.3 widening MANDATORY

Check 6.3 currently demands **10.3–10.5 V at TP2**. A low-tolerance board
legitimately regulating at **10.08 V** would **fail commissioning while working
perfectly**. Open item 5's widening to **~10.0–10.9 V** is no longer optional —
leaving it will send someone chasing a fault that does not exist.

---

## A3 — port pinout ⚠️ BLOCKED, superseded by A7

**Partial result: ~11 kΩ tip-to-sleeve, unpowered, one polarity.** Still to do:
the same measurement in **both probe polarities** — if they differ there are
protection diodes and the plain resistance model does not hold.

> **A 2-conductor TS plug CANNOT measure ring-to-sleeve.** Its sleeve spans both
> the ring and sleeve contacts inside the jack, tying them together before the aF4
> gets a say. Through a TS plug the reading is always a short, whatever the aF4
> does internally.

The ring question is now better attacked from the OEM side — see **A7**.

*Full method if a TRS breakout is on hand:* aF4 powered off and unplugged, TRS
breakout inserted, DMM on lowest ohms. Ring–sleeve expected short (< 1 Ω);
tip–sleeve high, both polarities.

## A4 — dongle output voltage, open-circuit vs loaded ⬜

The project carries a measured 10.37 V from the OEM dongle but not whether that
was open or loaded. The distinction sets what the hat should target.

1. Dongle powered through its splitter, 3.5 mm plug **not** in the aF4.
2. Assert the dongle (eWeLink toggle ON) and hold.
3. Measure tip–sleeve at the free plug → **V_open**.
4. Seat the plug into the aF4 through the breakout so you can probe connected.
   Assert again → **V_loaded**.

| Result | Meaning |
|---|---|
| V_open ≈ V_loaded | Port draws almost nothing; load-budget assumption confirmed |
| V_loaded materially lower | Port draws real current and the dongle has output impedance. **Not a problem for the hat** — the LM1117's output impedance is far lower and will hold 10.4 V |
| V_loaded < 9 V | Something is wrong with the dongle or breakout. Stop and re-check |

Both should sit comfortably inside the 9–11 V window. **Do this together with A8** —
same setup, same trigger.

## A5 — port input current and impedance 🟨 inferred, confirm under power

**Inferred: ~0.95 mA** from A3's 11 kΩ at 10.4 V. Negligible against an 18.7 mA
quiescent budget (20.0 mA during a feed) and F1's 0.10 A hold. Confirm powered:

1. Inline through the breakout: **dongle tip → 100 Ω → aF4 port tip.** Sleeves common.
2. Assert the dongle and hold.
3. Measure the voltage **across the 100 Ω**. Current = V / 100.

| Drop across 100 Ω | Current | Verdict |
|---|---|---|
| < 1 mV | < 10 µA | High-Z. Assumption confirmed, done |
| 1 – 100 mV | 10 µA – 1 mA | Negligible. **Expected — matches the 11 kΩ inference** |
| 0.1 – 2 V | 1 – 20 mA | Acceptable; recheck the AQY212GS load-current rating |
| > 2 V | > 20 mA | **Board-affecting.** Recheck LM1117 dissipation, F1's hold, AQY212GS on-resistance |

If readable, repeat with **1 kΩ** to test linearity — a resistive input scales
proportionally, a comparator or opto input will not. Compute **Z ≈ V_loaded / I**.

## A6 — port decay time ⬜

R3 is a 100 kΩ bleed returning the port to 0 V after a feed. Its time constant
depends on capacitance inside the port.

1. Dongle connected through the breakout, DMM on DC volts tip–sleeve.
2. Assert 20 s, then release.
3. Time the fall below **1 V**. Stopwatch is fine.

| Decay to < 1 V | Meaning |
|---|---|
| **Under 1 s** | Port self-discharges; R3's value irrelevant. No change |
| 1 – 10 s | Some capacitance. R3 100 kΩ still works; note the constant |
| **Over 10 s** | Consider dropping R3 to 10 kΩ. **Board change — decide now** |

**Expectation given A3:** the port's own ~11 kΩ is nine times stiffer than R3's
100 kΩ, so it should self-discharge quickly and R3 should prove harmless but
largely redundant. This test confirms or refutes that.

## A7 — OEM plug pinout ✅ DONE · ring question CLOSED

**Result: TIP + SLEEVE. Ring floating.** Black wire = sleeve (0 Ω), ring = O/L,
tip = the red wire. **Our pinout is correct — no J2 redesign.**

> **Reading note.** Tip-to-black measured 17–18 MΩ *and climbing*. That is not a
> resistance, it is the dongle's 10 V rail capacitance charging off the DMM's ohms
> source. It matched red-to-black on the board, which is what identifies tip and
> the red wire as the same node. The clean confirmation is **tip to the red
> terminal ≈ 0 Ω**.

### Decision: KEEP the ring-to-sleeve tie. No board change.

`aF4-MASTER-REFERENCE.md` already carries the fact that settles it, `[MEAS]
2026-07-10`: the link icon is **mechanical** — *"a bare plug with nothing attached
lights it. Jack insertion switch, no electrical sensing."*

A bare plug means all three contacts floating and the aF4 is happy. So the ring is
not a detect line, not a sense input, not anything. inD leaving it unwired agrees.

Both states are therefore demonstrated safe: **floating** (bare plug, OEM cable)
and **tied to sleeve** (what any TS plug does at the jack).

**The tie is also the more robust choice**, which earlier notes in this document had
backwards. Floating the ring on the board only genuinely floats it if a **TRS**
cable is used — a mono cable grounds it at the jack regardless, silently. Tying it
on the board makes behaviour cable-independent, which is what a design rebuilt
years later from the BOM needs. The BOM's "mono or stereo, either is fine" stands.

Residual risk is small enough to accept. To eliminate rather than reason it away:
a $5 TRS breakout and one ring-to-sleeve measurement on the aF4, unit off. **Not
worth holding the order for.**

---

*Original method, for reference:*

The teardown showed a **TRS plug with only two wires** at J2. Which two decides a
board question.

1. Dongle unplugged from power.
2. DMM on continuity.
3. Ring out **each** of the two J2 wires against the plug's **tip**, **ring**, and
   **sleeve** in turn.

| Result | Meaning |
|---|---|
| **Tip + sleeve** | Expected. Ring floats in the OEM cable → see the two routes below |
| **Tip + ring** | **Our pinout is wrong.** Stop and redesign J2 before anything else |

**If tip + sleeve, pick one before paying:**

| Route | What it means |
|---|---|
| **Match the OEM** | Leave J2's ring **unconnected** and **specify a TRS patch cable**. Ring floats end to end exactly as inD does it. Promotes the cable from "mono or stereo, either is fine" (as `aF4-esp32-trigger-BOM.md` says today) to a **design requirement** — a TS plug shorts ring to sleeve at the jack no matter what the board does |
| **Prove and keep** | Buy a TRS breakout, measure the aF4's ring to sleeve with the unit off, and keep the tie if it is already grounded |

Grounding a contact the OEM leaves floating is very likely harmless — but
"likely" is doing the work, and this is the last moment it is free to change.

## A8 — dongle pulse shape at TP_10V0 ⬜ NEW · high information

The dongle has a microcontroller, so inD's "ON for at least 10 seconds" may
describe the *dongle's* logic rather than the aF4's threshold. This separates them.

1. Dongle open, powered. Meter on **TP_10V0 / TP_GND**.
2. Trigger from the eWeLink app. Hold the toggle ON for ~30 s, then release.
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

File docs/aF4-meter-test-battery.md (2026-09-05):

# aF4 meter test battery

Bench procedure for closing the measurement-dependent open items.
Started **2026-09-01**. **None of it requires opening the aF4**, so the warranty
stays intact.

## Status at a glance

*Bench results below are the record. For what is still owed overall, see `STATUS.md`.*

| Test | What it settles | State |
|---|---|---|
| **A1** brick open-circuit | Open item 7, TVS standoff | ✅ **DONE — PASS**, headroom amber |
| **A2** loaded rail at splitter tap | LM1117 dropout headroom | ✅ **DONE — ACCEPT, no board change.** Forces the check-6.3 widening |
| **A3** port pinout | Port impedance | 🟨 ring question **closed by A7**; both-polarity check outstanding |
| **A4** dongle voltage open vs loaded | The 10.4 V target | 🟨 **V_open = 10.35→10.37 V**; V_loaded still to do |
| **A5** port input current | Open item 6 | 🟨 inferred (~0.95 mA), needs powered confirmation |
| **A6** port decay time | R3 bleed value | ⬜ not run |
| **A7** OEM plug pinout | J2 ring-to-sleeve tie | ✅ **DONE** — tip + sleeve, ring floats. **Keep the tie, no board change** |
| **A8** dongle pulse shape | Whether inD's 10 s is dongle logic | ✅ **DONE — pass-through, no fixed pulse.** B1's premise stands |
| **B1** hold-time sweep | 6 s vs 15 s | ⬜ confirmatory only |
| **B2** re-arm interval | R2 | ⬜ low value, confounded |
| **B3** held-high = one feed | Audit finding B5 | ⬜ high value |
| **C** commissioning | Go-live gate | ⬜ needs the built hat |

**Suggested run order:** ~~A7~~ → **A2** → A4 and A8 together → A5 confirm → A6 →
B3 → B1 → B2.

---

## Why the order matters

The rev E order is submitted to PCBWay but **not paid and not fabbed**. This is
the last cheap window to act on a measurement.

- **Group A can change the board.** Run before paying.
- **Group B only changes firmware.** Any time.
- **Group C needs the built hat.** It is the commissioning pass.

---

## What is already settled

**From measurement, 2026-09-01:**

- **Brick open-circuit 12.13 V, stable, centre-positive.** Well under the SMAJ13A's
  13 V standoff → no idle TVS conduction. **Open item 7 closed.**
- **~11 kΩ tip-to-sleeve** on the port (unpowered, through a TS plug) → about
  **0.95 mA at 10.4 V**. Against an 18.7 mA quiescent budget and F1's 100 mA hold
  that is negligible. **Open item 6 effectively answered**, pending A5.
- **The OEM dongle's plug is TRS but carries only two wires** — one conductor is
  unused. See the teardown section; this is board-affecting.

**From inD's own documentation** (full account in `aF4-vendor-docs-notes.md`):

- **5-minute minimum spacing** between feeds — vendor-stated, so our 300 s cycle
  is now sourced rather than derived.
- **A held-high line yields exactly one feed** — the Apex guide's worked example
  holds ON for 14 minutes and produces one feed. Independent corroboration of
  audit finding B5.
- **`R1` — inD publishes THREE hold times**: 6 s (Neptune Systems page, audit-verified
  2026-08-28), 10 s (inD Connect), 15 s (Hydros). The 6 s is genuine, just the most
  permissive. Design to 15 s; the 10 s pulse fails it. **20 s clears all three.**
- **Connecting the link port overrides the aF4's internal 24-hour schedule**, so an
  offline ESP32 means the fish are silently never fed.
- 12 V / 12.5 A brick confirms `R6`. Driving the port is documented, supported use.

---

## Decisions pending before payment

Three things could still change the board. Two are answerable at the bench in
under an hour.

1. ~~**A2's result.**~~ **CLOSED 2026-09-01 — ACCEPT, no board change.** Loaded
   minimum 11.77 V. Sits on the dropout boundary, but the output lands at ~10.47 V
   either way and threshold margin is ~1.5 V. **Forces the check-6.3 widening.**
2. ~~**J2's ring — tie or float.**~~ **CLOSED 2026-09-01 by A7 — keep the tie, no
   board change.** See A7 for the reasoning.
3. **R5's power rating.** It sits at ~96 mW against an 0805's 125 mW — **77 %**.
   A 0.25 W part is a drop-in. Raising the divider impedance is **not** available:
   it is the minimum-load ballast. Window closes at assembly.

---

## Prerequisites

| Item | Note |
|---|---|
| DMM | Any DC voltmeter. **Min/Max is NOT needed** — the load that matters is sustained. Film the meter during a feed if you want fine detail |
| **TRS** 3.5 mm breakout | Three separate pigtails, or a TRS screw-terminal adapter (~$5). A **TS breakout cannot do A3** — see the trap below |
| 100 Ω and 1 kΩ resistors | Bin stock, ¼ W fine |
| inD Connect dongle + eWeLink app | The known-good OEM signal source |
| Phone stopwatch | |
| Cup or container, ≥12 oz | |
| Sink or catch basin | |

**Never measure port current with the DMM in series in amps mode.** Burden voltage
is unpredictable, and a meter left in amps mode is the classic way to blow a fuse
or worse. A5 uses a series resistor — safer, and it yields input impedance free.

### Unit identity — recorded 2026-09-01

| Field | Value |
|---|---|
| Part number | **10102101** |
| Serial number | **130063** |

**The serial falls outside every range inD documents.** Their fan guide covers
`20XXX` / `60XXX` (full shutdown on over-temperature) and `100XXX` (standby with
continuous beeping, cooling continues, manual restart). A **130XXX is newer than
all of them**, so it most likely behaves like `100XXX` or newer — inference, not
documentation. Neither behaviour self-clears, and neither signals Home Assistant,
which is part of the case for dispense confirmation — a fault is invisible to HA even with the missed-feed watchdog running, because the pulse still succeeds. Master-reference item 20.

**Consequence worth having:** the link LED's flash-green-on-feed-signal is
documented as "newer units only". This unit is newer than any published range, so
**commissioning step 6.8 should be available.**

The 2024 solenoid manufacturing defect inD references should not apply to a unit
this recent.

---

## Setup S1 — the safe feed configuration

Used by every test that triggers a real feed. This is inD's own pre-use-rinse
arrangement, so it is a documented-safe way to run the unit.

1. aF4 upright on a counter near a sink. **Never on its side.**
2. Reservoir at least half full of plain water. **No food** — it only makes cycles
   messy and results harder to read.
3. Black intake tube fully submerged in a cup with ≥12 oz of water.
4. Grey output tube into the sink or a catch container. **Not the tank.**
5. Power on with a firm 3-second press. Solid green LED.
6. Feed quantity set to **1 LED (5 mL)** — shortest cycle, least water.

**Every triggered feed is auto-followed by a self-clean, so budget 5 minutes per
trial.** A five-point sweep is a 25-minute test. Do not rush it by re-triggering
early — you will only be measuring the spacing lockout. Never run the pump dry.

---

# Group A — board-affecting

## A1 — brick open-circuit voltage ✅ DONE

**Result: 12.13 V, stable, centre-positive. Open item 7 closed.**

TVS verdict **PASS** — well under the SMAJ13A's 13 V standoff, so no idle
conduction and no part change. Headroom verdict **AMBER** — this is the bottom of
the healthy band, and it is the *open-circuit* figure. Load only lowers it, which
is what makes A2 the priority.

*Method, for reference:* brick unplugged from the aF4, still on mains, DMM on DC
volts. **Black probe on the outer metal barrel, red probe INTO the centre hole.**

> On a male DC barrel plug the positive contact is a **hollow tube, not a
> protruding pin** — the pin lives in the female jack on the device. "5.5 × 2.5"
> means a 5.5 mm outer barrel and a **2.5 mm hole**, and that hole is the positive
> contact. A needle probe drops in. If it will not sit steady, push a short length
> of stripped solid-core wire or a male header pin into the hole and probe that.

> **The brick is rated 12.5 A.** Red probe slipping onto the outer barrel is a dead
> short across ~150 W. A 0 V reading almost always means lost contact, not a dead
> supply.

## A2 — loaded rail voltage at the splitter tap ⬜ THE PRIORITY

This is the actual input to the hat's LM1117, minus the SS14's ~0.3 V. The master
reference already establishes how tight it is:

| Brick | LDO input | Headroom to 10.47 V |
|---|---|---|
| 12.2 V | 11.90 V | 1.43 V ✓ |
| 12.0 V | 11.70 V | 1.23 V ✓, but a worst-case divider is **in dropout** |
| 11.6 V | 11.30 V | **in dropout** |

The aF4 is a 12.5 A load running a TEC, pump, solenoid and fan off this brick.
Sag is entirely plausible and has never been measured. **A1's 12.13 V starting
point means there is less headroom in hand than the design assumed.**

### Run it on the FIRST power-on — that is the worst case

The feeder has never been powered. **The first cool-down from room temperature is
the heaviest sustained load the brick will ever see**, because the TEC runs flat
out while it is far from setpoint. A2 taken now is genuinely worst case.

inD also requires a **pre-use rinse** before first use, so the two fold into one
session. This procedure is their rinse with the measurement layered on top.

#### Step 0 — before plugging anything in

- **The tank mount and cleaning tablet ship INSIDE the reservoir.** Remove both
  before adding water or the tablet dissolves.
- Uncoil the tubing (factory-fitted, no assembly). Check contents against the
  packing list; contact support rather than installing anything damaged.
- **Write down the serial number** from the underside sticker while the unit is
  still easy to tip.

#### Step 1 — meter hookup, using the dongle as a breakout

Better than holding probes in a barrel connector, and it frees your hands.

1. OEM splitter **female** end → power supply.
2. Splitter **short male** → inD Connect dongle.
3. Splitter **long male** → aF4.
4. **Leave the dongle's 3.5 mm plug OUT of the aF4** — it must not assert during
   the test. The dongle is only a powered breakout here.
5. **Alligator-clip the DMM across J1's two solder lugs on the dongle board** —
   the raw barrel input, ahead of any protection. Clips, not handheld probes: this
   needs to run unattended for half an hour.
6. DC volts. **Min/Max is not required** — the TEC is a *sustained* load, so a
   plain meter reads it correctly, and pump/solenoid events last seconds, not
   milliseconds. For fine detail during a feed, **prop a phone and film the meter**,
   then scrub back: ~30 readings/sec, better than most Min/Max modes.

7. **Sanity-check the rig before trusting it.** With mains connected and the aF4
   still switched off, the meter should read **≈ 12.1 V**, matching A1. Anything
   wildly different means the clips are wrong — stop and re-check. Record it as
   the **baseline**.

Cross-check once against **TP_12V**. Same reading → fine. TP_12V a few hundred mV
lower → D1 is in series and TP_12V is not the number you want; **trust the J1 lugs**.

#### Step 2 — fill, per inD's rinse procedure

- Reservoir at least half full of **warm** water.
- Long black intake tube **fully submerged** in a glass or bowl with ≥ 12 oz.
- Grey output tube into the sink or a catch container. Unit upright.
- **Temperature setting 3 or higher if convenient**, but do not fuss: nothing
  freezes in half an hour from room temperature. The freezing risk applies only to
  running for *hours* at setting 1 with plain freshwater. Load is unaffected either
  way — during pull-down from ambient the TEC draws full power whatever the setpoint.
- Power on with a firm **3-second** press. Wait for solid green.

#### Step 3 — cool-down, 20–30 min (sustained maximum load)

Leave it running with the meter recording. Note the reading a minute or two in,
then walk away and come back for the captured minimum.

> **Watch the temperature LEDs on this first run.** All five flashing together is
> an over-temperature fault, and *when* it starts is the diagnosis: **immediately**
> = fan failure; **within 3 h** = bad probe; **after 3 h** = genuinely hot. This
> unit's serial is outside every documented range, so **record whether it beeps and
> holds in standby or shuts down outright** — that is a new data point and it tells
> you which recovery to expect. It will not self-clear either way.

#### Step 4 — rinse feeds (transient load on top of the TEC)

Still recording, run inD's rinse: press **Feed Now**, let the full cycle *including
auto-clean* finish, and repeat **two more times** — about 5 minutes each.

If nothing dispenses, run one **Auto-Clean** and retry Feed Now before worrying.

#### Step 5 — shut down

Power off and drain the reservoir.

**Completed 2026-09-01.** inD's pre-use rinse requirement is satisfied; the unit
has been flushed three times and is ready for first real use.

#### Record

The idle reading, and the **minimum across the whole session**.

| Minimum | Verdict |
|---|---|
| **≥ 12.2 V** | PASS — the headroom assumption holds |
| 12.0 – 12.2 V | Marginal. A worst-case divider rides dropout. Functional, unregulated |
| 11.6 – 12.0 V | **CONCERN** — nominal parts enter dropout during feeds |
| **< 11.6 V** | **Board-affecting.** Shared-rail approach needs rethinking — separate supply for the hat, or a different regulator topology |

Dropout is **not a safety failure**: the LM1117 degrades to roughly V_IN − 1 V,
still inside the 9–11 V window, so feeds still trigger. What is lost is regulation
and ripple rejection. But if this lands under 12.0 V, say so **before paying** —
far cheaper to change now than after assembly.

Short sub-100 ms transients would need a scope; do not chase them — the hat's
10 µF input cap rides through those anyway. Sustained sag is the whole question.

**Report four numbers:** baseline (aF4 off), idle with the TEC running, lowest
during cool-down, lowest during a feed.

**Given A1's 12.13 V unloaded, anything but a small sag lands in the marginal band
immediately.** That is precisely what is worth knowing before paying.

> **Two cautions.** The dongle is an open board carrying 12 V — keep it off
> anything conductive and never bridge J1's lugs, which is a dead short across a
> 12.5 A supply. And do not short the boost output; live 10 V rail with an
> inductor behind it.

### A2 VERDICT, 2026-09-01 — ACCEPT. No board change.

| Reading | Value |
|---|---|
| Baseline, aF4 off | 12.13 V |
| Idle, TEC running | 11.84 → 11.86 V (sag 0.29 V, stable) |
| **Minimum during feed** | **11.77 V**, recovering immediately |
| Repeatability | **Floor held at 11.77 V across all three rinse cycles** |

The feed adds only **0.09 V** over the TEC load — pump and solenoid are minor
next to the TEC, so there is no transient risk hiding behind the steady figure.
**Confirmed over three complete feed + auto-clean cycles**: same floor each time,
immediate recovery, no drift or droop as the run went on — which is where a
genuinely marginal supply would have shown itself.
Total sag from baseline 0.36 V. Measured under the heaviest conditions the unit
will ever see: first pull-down from ambient, TEC flat out, feed stacked on top.

**Worst case:** 11.77 V − 0.3 V (SS14) = **11.47 V at the LDO**, giving exactly
**1.00 V** headroom against ~1 V of dropout — precisely on the boundary.

**Why that is a non-event:**

1. **In dropout the output lands where regulation would have put it.**
   11.47 − 1.0 ≈ **10.47 V**, versus a 10.47 V regulated target. The two answers
   converge at this input voltage.
2. **Threshold margin is ~1.5 V.** For the output to fall under 9 V the brick
   would have to sag to ~10.3 V. Nothing in a feed cycle approaches that.
3. **Dropout makes the divider tolerance BETTER, not worse.** With the pass device
   saturated, V_OUT follows V_IN regardless of what R4/R5 ask for — so the
   worst-case-high stack the audit flagged simply sits at ~10.47 V instead of
   10.88 V. Real spread becomes ~10.08–10.5 V, **tighter than designed**.
4. **~1 V dropout is the audit's conservative figure.** At 20 mA the true value is
   likely lower, in which case it regulates normally and none of this applies.
5. **What is lost — regulation and PSRR — is not needed.** The port is a threshold
   input with a ≥10 s hold, not an analog input. It cannot tell the difference.

**Considered and rejected:** retargeting the divider lower to guarantee regulation.
That trades a known-good 10.5 V for a lower voltage with less threshold margin, to
fix something that is not causing harm.
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

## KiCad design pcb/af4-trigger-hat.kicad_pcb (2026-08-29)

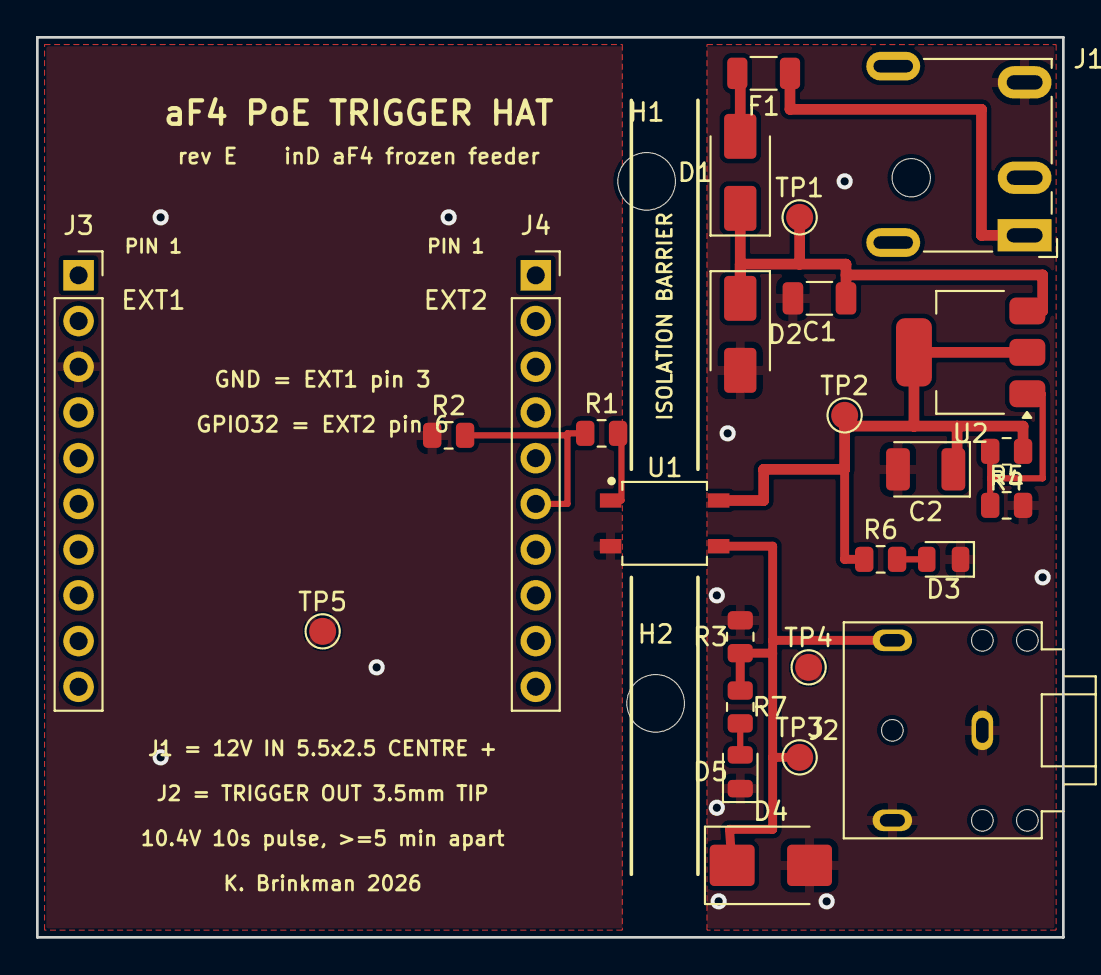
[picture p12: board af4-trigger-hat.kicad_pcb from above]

Board: 2 copper layers, 57.0 x 50.0 mm, 28 parts (0 on the bottom side), 12 nets.

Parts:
C1: 10uF/50V; C_1206_3216Metric
C2: 10uF/25V; CP_EIA-3528-21_Kemet-B
D1: SS14; D_SMA
D2: SMAJ13A; D_SMA
D3: GRN; LED_0805_2012Metric
D4: SMBJ13CA; D_SMB
D5: YEL; LED_0805_2012Metric
F1: 010; R_1206_3216Metric
H1, H2: M3; MountingHole_3.2mm_M3_ISO7380
J1: PJ-079BH; BarrelJack_CUI_PJ-079BH_Horizontal
J2: SJ1-3523N; Jack_3.5mm_CUI_SJ1-3523N_Horizontal
J3: EXT1; PinSocket_1x10_P2.54mm_Vertical
J4: EXT2; PinSocket_1x10_P2.54mm_Vertical
R1: 220R; R_0805_2012Metric
R2: 10k; R_0805_2012Metric
R3: 100k; R_0805_2012Metric
R4: 121R; R_0805_2012Metric
R5: 887R; R_0805_2012Metric
R6: 1k0; R_0805_2012Metric
R7: 6k8; R_0805_2012Metric
TP1: 12V; TestPoint_Pad_D1.5mm
TP2: 10V4; TestPoint_Pad_D1.5mm
TP3: TIP; TestPoint_Pad_D1.5mm
TP4: GND; TestPoint_Pad_D1.5mm
TP5: GNDL; TestPoint_Pad_D1.5mm
U1: AQY212GS; AQY212GS_SOP4_Panasonic
U2: LM1117MPX-ADJ; SOT-223-3_TabPin2

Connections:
+10V4: C2.1, R4.1, R6.1, TP2.1, U1.4, U2.2
+12V: C1.1, D1.1, D2.1, TP1.1, U2.3
+12V_F: D1.2, F1.2
+12V_RAW: F1.1, J1.1
ADJ: R4.2, R5.1, U2.1
FEEDLED: D5.2, R7.2
GNDL: J3.3, R2.1, TP5.1, U1.2
GNDP: C1.2, C2.2, D2.2, D3.1, D4.2, D5.1, J1.2, J2.R, J2.S, R3.2, R5.2, TP4.1
GPIO32: J4.6, R1.1, R2.2
LED_A: R1.2, U1.1
PWRLED: D3.2, R6.2
TIP: D4.1, J2.T, R3.1, R7.1, TP3.1, U1.3

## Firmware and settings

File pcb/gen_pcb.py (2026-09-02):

#!/usr/bin/env python3
"""Generate the aF4 PoE Trigger Hat (rev E) KiCad PCB.

rev E is rev D with the corrected U1 land pattern, relabelled. Copper,
outline, drills, BOM and placements are identical to the final rev D
package; only the revision string moved. The letter was advanced because
rev D fab data had already been released to PCBWay and was then found
invalid, so two different file sets would otherwise both answer to "rev D".

Coordinates are expressed in the Olimex ESP32-POE-ISO Rev N board frame, so the
socket positions come straight from the vendor CAD:
  ESP32 outline  x 90.15..118.15   y 90.00..188.15
  EXT1 pin1      (91.44, 123.22)   pin3 = GND    (91.44, 128.30)
  EXT2 pin1      (116.84, 123.22)  pin6 = GPIO32 (116.84, 135.92)
"""
import re, os, math

FPDIR = "/usr/share/kicad/footprints"
# project-local footprints take precedence over the stock KiCad libraries.
# aF4.pretty holds parts whose stock footprint is wrong for the part we buy -
# see AQY212GS_SOP4_Panasonic.kicad_mod.
LOCALFP = os.path.join(os.path.dirname(os.path.abspath(__file__)), "footprints")

MIN_SLOT = 0.70   # PCBWay will not route a slot narrower than this; some library
                  # footprints (SJ1-3523N) specify 0.40 mm blade slots, which would
                  # trigger an engineering query. Widened here, annular ring checked.

BX0, BX1 = 89.15, 146.15      # 57.0 mm
BY0, BY1 = 110.00, 160.00     # 50.0 mm
GAP_L, GAP_R = 121.65, 126.35  # isolation frontier (logic | power)

nets = {}
def net(name):
    if name not in nets:
        nets[name] = len(nets) + 1
    return nets[name]
net("")

# ------------------------------------------------------------------- helpers
def load(lib, name):
    for root in (LOCALFP, FPDIR):
        path = os.path.join(root, lib + ".pretty", name + ".kicad_mod")
        if os.path.exists(path):
            return open(path).read()
    raise FileNotFoundError("%s:%s not found in %s or %s" % (lib, name, LOCALFP, FPDIR))

def sexp_span(text, start):
    i = text.index("(", start)
    d, k = 0, text.index("(", start)
    while k < len(text):
        if text[k] == "(":
            d += 1
        elif text[k] == ")":
            d -= 1
            if d == 0:
                return i, k + 1
        k += 1
    raise ValueError("unbalanced s-expression")

def xf(fx, fy, px, py, rot):
    """KiCad footprint-local -> board coordinates."""
    a = math.radians(rot)
    return (fx + px * math.cos(a) + py * math.sin(a),
            fy - px * math.sin(a) + py * math.cos(a))

PADS = {}   # (ref, padnum) -> (x, y)
WIDENED = []
FPS = []

def place(lib, fpname, ref, value, x, y, rot=0, netmap=None):
    t = load(lib, fpname)
    netmap = netmap or {}

    # header: handle both quoted (KiCad 6/7) and bare (legacy) footprint names
    m = re.match(r'\(footprint\s+("?)([^"\s)]+)\1', t)
    hdr_end = m.end()
    t = ('(footprint "%s" (layer "F.Cu")\n  (at %.4f %.4f%s)'
         % (m.group(2), x, y, "" if rot == 0 else " %g" % rot)) + t[hdr_end:]
    # drop the footprint's own layer/tedit tokens that now duplicate ours
    t = re.sub(r'\(version \d+\)\s*', '', t, count=1)
    t = re.sub(r'\(generator [^)]*\)\s*', '', t, count=1)
    t = re.sub(r'\(layer "?F\.Cu"?\)\s*', '', t, count=1)
    t = re.sub(r'\(tedit [^)]*\)\s*', '', t, count=1)

    t = re.sub(r'\(fp_text reference ("?)[^"\s)]*\1',
               '(fp_text reference "%s"' % ref, t, count=1)
    t = re.sub(r'\(fp_text value ("?)[^"\s)]*\1',
               '(fp_text value "%s"' % value, t, count=1)
    s = t.find('(fp_text value')
    if s >= 0:
        a, b = sexp_span(t, s)
        blk = t[a:b]
        if " hide" not in blk:
            blk = re.sub(r'\(layer "?F\.Fab"?\)', lambda mm: mm.group(0) + " hide", blk, count=1)
        t = t[:a] + blk + t[b:]

    # strip any Edge.Cuts geometry the footprint carries (jack nose notches):
    # our board outline is a plain rectangle and the noses simply overhang it.
    for tag in ("(fp_line", "(fp_arc", "(fp_circle", "(fp_poly", "(fp_rect"):
        out, i = [], 0
        while True:
            j = t.find(tag, i)
            if j < 0:
                out.append(t[i:]); break
            a, b = sexp_span(t, j)
            blk = t[a:b]
            out.append(t[i:a])
            if 'Edge.Cuts' not in blk:
                out.append(blk)
            i = b
        t = "".join(out)

    # pads: rotate pad angles with the footprint, attach nets, record positions
    out, i = [], 0
    while True:
        j = t.find("(pad ", i)
        if j < 0:
            out.append(t[i:]); break
        out.append(t[i:j])
        a, b = sexp_span(t, j)
        pad = t[a:b]
        num = re.match(r'\(pad "?([^"\s]*)"?', pad).group(1)
        at = re.search(r'\(at ([-\d.]+) ([-\d.]+)(?: ([-\d.]+))?\)', pad)
        px, py = float(at.group(1)), float(at.group(2))
        if num:
            PADS[(ref, num)] = xf(x, y, px, py, rot)
        if rot:
            ang = float(at.group(3)) if at.group(3) else 0.0
            pad = (pad[:at.start()] + "(at %g %g %g)" % (px, py, (ang + rot) % 360)
                   + pad[at.end():])
        # manufacturability: widen any slot narrower than MIN_SLOT
        def widen(mm):
            a, bb = float(mm.group(1)), float(mm.group(2))
            na, nb = max(a, MIN_SLOT), max(bb, MIN_SLOT)
            if (na, nb) != (a, bb):
                WIDENED.append((ref, num, a, bb, na, nb))
            return "(drill oval %g %g)" % (na, nb)
        pad = re.sub(r'\(drill oval ([\d.]+) ([\d.]+)\)', widen, pad)
        if num in netmap:
            n = netmap[num]
            pad = pad[:-1] + ' (net %d "%s"))' % (net(n), n)
        out.append(pad)
        i = b
    FPS.append("".join(out))

def PP(ref, pad):
    return PADS[(ref, str(pad))]

segs, vias, gfx = [], [], []
def seg(p1, p2, netname, layer="F.Cu", w=0.35):
    segs.append('  (segment (start %.4f %.4f) (end %.4f %.4f) (width %.2f) '
                '(layer "%s") (net %d))' % (p1[0], p1[1], p2[0], p2[1], w, layer, net(netname)))

def route(pts, netname, w=0.35, layer="F.Cu"):
    for p1, p2 in zip(pts, pts[1:]):
        if p1 != p2:
            seg(p1, p2, netname, layer, w)

def via(x, y, netname):
    vias.append('  (via (at %.4f %.4f) (size 0.9) (drill 0.45) '
                '(layers "F.Cu" "B.Cu") (net %d))' % (x, y, net(netname)))

def line(x1, y1, x2, y2, layer, w=0.15):
    gfx.append('  (gr_line (start %.4f %.4f) (end %.4f %.4f) (stroke (width %.2f) '
               '(type solid)) (layer "%s"))' % (x1, y1, x2, y2, w, layer))

def text(s, x, y, layer="F.SilkS", size=1.0, thick=0.15, rot=0, just=None):
    j = ' (justify %s)' % just if just else ''
    gfx.append('  (gr_text "%s" (at %.4f %.4f%s) (layer "%s") (effects (font '
               '(size %.2f %.2f) (thickness %.2f))%s))'
               % (s, x, y, "" if rot == 0 else " %g" % rot, layer, size, size, thick, j))
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

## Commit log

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2026-07-17 Enclosure v3: lengthen input end 4mm to clear gland nut
    Physical fit check: input gland thread stub + locknut protrude 5.0mm
    past the inner wall but the wall-to-board gap was only 4.85mm, so the
    board rode the nut and couldn't seat on its standoffs. Input wall moved
    out 4mm (case now 159mm long); RJ45 recesses 4mm into a tunnel enlarged
    to z -1.5..16.5 for plug boot clearance; wing/shield relief pockets
    removed (now inside cavity). Fit re-verified: zero interference
    case/board/nut, 3.85mm nut-to-board clearance.
    [aF4-trigger-case.step, aF4-trigger-case.stl, aF4-trigger-lid.stl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]
2026-07-17 Lid: add registration lips to short sides
    26mm lips on the input/output edges (vs 30mm on the long sides) to
    clear the O9 corner lid bosses by ~1.4mm. Verified zero interference
    lid/case and lid/board.
    [aF4-trigger-case.step, aF4-trigger-lid.step, aF4-trigger-lid.stl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]
2026-07-18 Enclosure v4: RJ45 snout restores tight jack window
    v3 print feedback: the plain 4mm tunnel left the jack visibly recessed
    behind a tall loose opening. Fuse a 1mm pad on the input wall's inner
    face around the jack (snout face 0.1mm off the jack face) and cut the
    tight v1 window (0.5mm reveal) through the 3.9mm-deep snout, plus a
    12x1.8mm latch-relief notch under the aperture (latch-down jack).
    Snout clears the gland locknut by 1.7mm. All interference checks
    clean: case/lid vs board, simulated nut vs case/board.
    [aF4-trigger-case.step, aF4-trigger-case.stl, aF4-trigger-lid.step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]
2026-07-18 Enclosure v5: flush RJ45 restored; width, not length, clears gland nut
    v3/v4 direction reversed per print feedback: recessed jack looked and
    worked worse than v1's flush fit. Input wall returns to the v1 position
    (case back to 155mm long, tight flush window + wing/shield reliefs,
    snout and latch notch removed). Instead, the left wall moves out 8mm
    more (case now 59.7mm wide) and the input gland shifts left to x=77.5,
    putting its locknut entirely beside the board footprint (2.1mm clear of
    the board edge) — the board seats flush regardless of nut protrusion.
    Buck pocket, lid ribs, tabs all follow parametrically; protoboard bay
    and output gland shift ~4mm left with case center.
    Checks: nut v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
    [aF4-trigger-case.step, aF4-trigger-case.stl, aF4-trigger-lid.step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]
2026-07-18 HA: adopt af4-feeder device, document entities and DHCP reservation
    Add af4-feeder.yaml as the source-of-truth ESPHome config (Device Builder
    on the Unraid server holds a copy; changes are pasted there then flashed OTA).
    Document the exposed entities, the HA-side helpers and scheduled-feed
    automation, and why feed counting lives in HA rather than on-device.
    Record the .230 -> .55 DHCP move that broke HA discovery with Errno 113,
    fixed by reserving MAC 20:E7:C8:74:A6:D7 at 192.168.1.55 in OPNsense dnsmasq.
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2026-07-19 TVS: swap SMAJ12A for P6KE12CA bidirectional (part on hand)
    Leaded DO-15 legs splice into the cable far more easily than SMA
    end-caps, and bidirectional means no orientation to get wrong -- the
    reversed-TVS warnings come out of the guide and diagrams.
    Spec note: the 10.2 V standoff sits nominally below the 10.4 V line
    (SMAJ12A's is 12 V). Breakdown doesn't start until ~11.4 V, so the
    line just rides the leakage knee -- uA into the high-impedance trigger
    port, invisible to feeder and buck. Upside: spikes clamp closer to the
    line than the SMAJ12A's ~13.3 V would.
    Touches the BOM row, assembly guide 4/7, layout detail panel 2, and
    the TVS callouts in the solder-side, wiring, and system diagra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
2026-07-19 Enclosure v6: DC-099 panel jack replaces input PG7 gland
    Input wall now takes a DALQUIS DC-099 threaded barrel jack (5.5x2.5,
    12.2mm hole, teardrop crown lowered to 6.5mm for its ~14mm flange) —
    the inD splitter's male tap plug connects externally; jack pigtails
    run polyfuse -> buck inside. Same hole position; smaller locknut keeps
    all v5 board clearances. Output PG7 gland unchanged. STLs regenerated
    and geometry-verified; notes/BOM/reference/assembly guide updated.
    [aF4-trigger-case.step, aF4-trigger-case.stl, aF4-trigger-lid.step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]
2026-07-19 R3: replace 2.2k with 5x10k parallel bank (2k, on-hand stock)
    - layout SVG: 3 flat rows + 2 piggybacked pairs; screw rows kept clear
    - BOM: R3 spec + substitute note (single 2-2.2k identical)
    - assembly guide: R3 bank mounting note, 2.0k meter checks, updated
    band-color warning, bench preload recipe
    - reference: preload implementation note
2026-07-19 Revert R3 5x10k bank — 2.2k resistors ordered
    Restores single 2.2k R3 (layout, BOM, guide, reference). The 5x10k
    parallel bank was a stock workaround; proper parts are on the way.
    Buck already bench-set to 10.38 V under a 2k load — unchanged, the
    2.2k service load difference is negligible.
2026-07-20 Docs sweep: fix stale v6/post-adoption references
    - System diagram: input wall label PG7 gland -> DC-099 12V jack (v6)
    - BOM/assembly/README/reference: af4-feeder.yaml is the config source
    of truth (BOM YAML is concept sketch); button entity is
    button.af4_feeder_feed; assembly guide 5/8 reflect flashed device
    and existing HA schedule helpers/automation
2026-07-26 Protoboard SVGs: vertical R1/R2, board cut size, DC-099 input
    Both views lagged the assembly guide on three points:
    - R1/R2 now drawn standing vertically on a one-pitch footprint, with
    each bent lead landing in a shared GPIO13 junction hole (marked as a
    pad, with sleeving shown). The old flat R2 spanned a single pitch,
    which no 1/4 W axial body will do. R3 stays flat across 3 pitches.
    - Board note: cut ~30x33 mm, 25x25 mm / 9x9 grid as the minimum.
    - Detail (1) and the off-board panels route the splitter through the
    DC-099 panel jack (enclosure v6) rather than straight to the polyfuse;
    labels now read DC-099 red (+) / black (-).
    Also added the red-red-brown vs red-red-red meter w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
2026-07-27 Rev C: replace buck module with on-board LM1117T-ADJ linear regulator
    Three Amazon MP1584EN modules failed (light-load buzz + torque-seal
    death, missing pot screw, open trimmer wiper). Load is ~15mA/24mW —
    a linear reg's job, and the >=9V port threshold is a window, not a
    setpoint, so fixed 1% resistors replace the trimpot entirely.
    - LM1117T-ADJ (TO-220) + R4 121R / R5 887R -> 10.41V, on the
    protoboard's 12V side; C1 10uF in, C2 10uF tantalum out
    - R3 preload deleted (divider is the minimum load)
    - Polyfuse 500mA -> 100mA MF-R010 (right-sized for ~15mA draw)
    - TVS P6KE12CA -> P6KE15CA (standoff now above the working voltage)
    - Buck wall pocket in enclosure now vestigial; no reprint nee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
2026-08-27 pcb: fix README SMD count 20->17, compute counts in make_package
2026-08-28 pcb: fix three non-existent MPNs, split LED series resistors
    Three part numbers in the rev D BOM did not exist. All were
    well-formed under their manufacturer's naming scheme but return no
    stocked part; PCBWay's sourcing flagged one and silently substituted
    the other two.
    F1 1206L010/60YR -> 1206L010/60WR
    The 1206L suffix is a reel-quantity code (WR=3000, YR=4000);
    the 60 V value ships only as /60WR. Trip current is 0.25 A,
    not the 0.30 A the docs claimed.
    C1 GRM31CR71H106KA12L -> GRM31CR61H106KA12L
    R7=X7R, R6=X5R. Murata makes no 10 uF 50 V X7R in 1206; that
    C/V needs a 1210. X5R is correct for input bulk.
    D5 APT2012SYC -> APT2012SYCK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
    [Quotation T-3P4W1125728A - aF4 trigger hat rev D - customer reply.xlsx, af4-trigger-hat-BOM.csv, af4-trigger-hat-BOM.xlsx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]
2026-08-28 pcb: rebuild U1 land pattern from Panasonic's drawing
    U1 was on SO-4_4.4x2.3mm_P1.27mm, a 1.27 mm-pitch generic SO-4 whose
    library description points at an OPTEK OPIA403. The AQY212GS is a
    Panasonic GU SOP4 at 2.54 mm pitch, so every pin missed its pad by
    0.635 mm. The board could not be built and the Gerbers sent to PCBWay
    were invalid.
    U1 now uses a project-local footprint authored from the "Recommended
    mounting pad" drawing in semi_eng_gu_sop4_1a.pdf:
    pcb/footprints/aF4.pretty/AQY212GS_SOP4_Panasonic.kicad_mod
    pad 0.8 mm across pitch x 1.2 mm along the lead axis
    centres 2.54 mm on pitch, 6.00 mm across the span
    gen_pcb.py's load() now prefers a project-local footprints/ directory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
    [af4-trigger-hat-BOM.csv, af4-trigger-hat-BOM.xlsx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]
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2026-09-01 Fold bench findings into test battery; add A7 and A8
    A1 passes and closes open item 7; the 11k reading effectively answers
    open item 6. OEM teardown found a TRS plug with two wires, which makes
    J2's ring-to-sleeve tie an open board question. A7 resolves it in two
    minutes; A8 tests whether the dongle emits a fixed-width pulse.
2026-09-01 A2 passes: bench work clears the rev E order
    Loaded minimum 11.77 V. Sits on the LM1117 dropout boundary, but the
    output lands at ~10.47 V either way and threshold margin is ~1.5 V.
    Dropout also tightens divider tolerance rather than worsening it.
    All three board-affecting questions (A1, A2, A7) closed with no change.
    One mandatory consequence: commissioning check 6.3 must widen to
    10.0-10.9 V or a good board fails it.
2026-09-01 A2: 11.77 V floor confirmed across all three rinse cycles
    Same floor each cycle with immediate recovery and no drift, which is
    where a marginal supply would have shown itself. Pre-use rinse complete.
2026-09-01 Fold bench + vendor findings into reference docs
    R1 retagged [VENDOR] >=15s. inD publishes three conflicting hold times
    (6s Neptune page, 10s inD Connect, 15s Hydros) - the 6s is genuine and
    audit-verified, just the most permissive. Design to the longest.
    Master reference gains seven measured facts; the internal-24h-timer open
    question is closed and resolved opposite to the prior assumption; three
    'still unverified' items struck through as closed.
    Check 6.3 widening is now mandatory with measurements behind it.
2026-09-01 Firmware: 20s pulse, boot lockout, web auth; widen commissioning
    af4-feeder.yaml: 20s pulse + 290s tail = 310s cycle, clearing both the
    15s hold and the 5-min spacing with margin. Flash-persisted feed_in_flight
    global closes the on_boot lockout gap - a reboot mid-cycle is detected and
    serves a 300s recovery lockout. web_server auth added.
    Assembly guide: check 6.2 widened to 11.4-12.0V and 6.3 to 10.0-10.9V.
    Both would have failed a good board against the measured 11.77V rail.
    Added 6.7/6.8 link-LED checks.
2026-09-01 yaml: ethernet clk nested block, not legacy clk_mode
    Reconciled against the live Device Builder copy. The rewrite had
    inherited clk_mode: GPIO17_OUT from its pre-rev-D base; the deployed
    copy already uses the nested clk: block and compiles on ESPHome
    2026.8.2. PoE-only board with no wifi fallback, so this one matters.
    Also corrects a stale assembly-guide section reference.
2026-09-01 docs: boot-recovery is verified by state, not by log
    The on_boot message fires before any log client can attach and is
    never observable; the old §6 note sent you looking for it. Verify by
    Feed Lockout ON at low uptime, and check uptime first — a Restart
    that did not register reads as a broken lockout.
2026-09-01 enclosure: four light-pipe sight holes + engraved lid label
    Adds stepped Ø3.5→Ø2.6 light-pipe bores over PWR1 and LNK1 on the Olimex
    board and converts the two hat holes (D3, D5) to the same profile. ACT1 and
    CHRG1 deliberately have no hole - ACT1 sits 0.361 mm inside the hat footprint.
    Engraves 'aF4 PoE / TRIGGER' 0.8 mm into the outer face. Adds solid pipe-vs-PCB
    interference tests. Case geometry unchanged (STL byte-identical).
    [aF4-trigger-lid.step, aF4-trigger-lid.stl, af4_lid_inframe.step]
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2026-09-02 assembly: full light-pipe cutting, finishing and fitting spec
    Adds the seated-protrusion check (20.6 / 8.0 mm off the lid inner face) so
    length can be verified without the board, the one-sided tolerance rule, ends-
    only polishing, and the adhesive warnings (no CA, no solvent cement).
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2026-09-02 Full review 2026-09-02: fix diagrams, reconcile ledger, record order YB1800644
    Rev E is ordered, quoted, paid and in fabrication. This is the sweep taken after
    the design stopped moving, so it closes drift rather than defects.
    The diagrams were the real finding. Both were dated 2026-08-27 and had never been
    touched, so between them they still asserted R6 = 10k / R7 = 10k -- the exact
    under-driven-green-LED defect corrected on 2026-08-28 -- plus ">=9 V held >6 s",
    a 10 s pulse, the withdrawn 4.3 mm isolation figure, "rev D", and a TP2 band that
    would fail a good board. A diagram is what someone reads first when rebuilding
    and a resistor value is what they would copy without questioning. Both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
    [Quotation T-3P6W1125728A - aF4 trigger hat rev E - quoted BOM 2026-09-02.xls]
2026-09-02 Secrets: externalise to gitignored secrets.yaml, rotate all three
    The API encryption key, the OTA password and the web_server password were all
    committed in plaintext to a PUBLIC repo. The 2026-08-28 audit noted this as
    "related hygiene" at the tail of the web-server finding, which undersold it: it
    described the repo without describing its visibility.
    The sharp part was the sequence. web_server: auth: was added on 09-01 precisely
    to close an unauthenticated LAN control path, and the commit that closed it
    published the credential. The hole was the same size, moved from the LAN to the
    internet.
    All three now resolve through !secret against a gitignored secrets.yaml, AND all
    three are rotated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
2026-09-02 Record the HA automations as they actually are; withdraw item 17
    Read the live Home Assistant config rather than trusting this repo's
    description of it, and the repo was wrong in the direction that matters least
    for safety and most for trust: it under-described work that already existed.
    automation.reef_tank_af4_scheduled_feed is not "presses the button at each feed
    time", which is all these docs said. It checks two interlocks before pressing --
    the feeder lockout AND the sump return pump, because the feeder discharges into
    the sump and without the return the food never reaches the display. It then
    waits up to 15 s for the on-device lockout to assert, which is proof the pulse
    started, since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
2026-09-02 Firmware was already live: close item 11, split the secrets rotation
    Two corrections and one near-miss.
    ITEM 11 WAS CLOSED ON 09-01 AND NOBODY NOTICED. The device reports its own
    firmware as built 2026-09-01 18:54:20; the last YAML commit that evening was
    18:51:33. It was installed three minutes after it was written. GPIO32, the 20 s
    pulse, the 310 s cycle, the boot lockout and web auth have been live since.
    Yesterday's review copied the stale row forward and called it "the only thing
    standing between the current state and a working system", which was wrong. The
    check that settled it cost nothing: the device publishes its build timestamp as
    an entity. Ask the system what it is running.
    THE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
2026-09-05 One ledger: strip live status from the four docs that still carried it
    The reorganisation moved the entry path but left four documents describing
    current state, using four incompatible item numberings for the same work:
    §8 called the headers item 12, pcb-notes called them item 2, the meter test
    battery tracked "open items 1-14" whose item 1 (the PCBWay requote) had been
    done since 09-02, and the archived handoff called them item 3.
    STATUS.md is now the only place that says what is open.
    - §8 keeps the numbering registry and the dated record of how each item
    closed, under a banner saying it is not current state.
    - pcb-notes' "Open items" becomes "Board notes and standing cautions"; its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
2026-09-05 Fix defects a cold-read test found, including two introduced yesterday
    Simulated a fresh session following the new project instructions literally and
    made it answer eight questions using only the entry path. It answered all eight
    and never opened archive/, but it found six real defects.
    Two were introduced by the restructure:
    - STATUS.md had assigned items 19 and 9 to the ship-date check and the J2 BOM
    flags. Both numbers were already spent in the §8 registry (19 is the
    silkscreen string, 9 is the closed web_server auth item). They came from the
    archived handoff's numbering, for the only two rows never cross-checked
    against §8 - the exact failure the standing correction warns abo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
2026-09-11 Add 09/11/26 PCBWay EQ reply: J3/J4 fitted on wrong face, rework requested
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2026-09-12 Accept PCBWay's J3/J4 rework; close item 23, open item 26
    PCBWay reworked one board and photographed both faces. The A3 defect is
    fixed: socket bodies on the bottom face, pin tails and solder on top,
    pin 1 unmoved, both seated flush and square, isolation band clean and
    R1/R2 undamaged. The apparent J3 overhang past the board edge is
    perspective on an 8.50 mm body, not lateral offset.
    Two workmanship points from the 09-11 reply were not fixed - pin 10 of
    each socket row carries excess solder with burnt flux, and the bottom
    face is uncleaned at that end. Accepted rather than reworked again:
    five boards are being built, one is needed, and both are five minutes
    with an iron and IPA. A second re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
2026-09-16 Raise the hat 1.5 mm to clear the Olimex cap beside DCDC1; add §6.3, item 27
    Calipered 2026-09-16 from the ESP32's bottom face: the electrolytic cap beside
    DCDC1 tops out at 13.4 mm against a hat underside at 12.62, a 0.78 mm collision.
    DCDC1 is 11.5 and UEXT1 11.2. The enclosure script had checked the hat against a
    hand-typed 4.40 mm UEXT height, so no tall Olimex part was ever tested.
    - af4_enclosure_ocp.py: HAT_LIFT 1.50 (HAT_Z 14.118), IZ1 25.00, external
    39.9 mm. TALL_PARTS carries the measured heights; scalar clearance checks,
    a pin-engagement check and a hat-slab solid test replace the 4.40 assumption,
    and the case-vs-ESP32 envelope rises to the tallest part.
    - af4_hat_dummy_o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
2026-09-16 Add verify_enclosure.py, a numpy-only check of the printed enclosure meshes
    Reads the exported case and lid STLs, so it runs in any shell, unlike the
    cadquery-ocp scripts. Checks bounding boxes, standoff tops by ray cast, the hat
    and ESP32 envelopes by ray-parity point-in-mesh behind a positive control, both
    jack-hole axes, and the hat slab against TALL_PARTS and the vendor ESP32 mesh.
    Validated against the committed exports: with the pre-lift parameters every mesh
    check passes and the vendor-mesh check independently finds the cap collision
    (13.15 vs 12.62). With the current parameters it fails five checks, which is the
    acceptance test for item 27.
    The lid print file does not depend on HAT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
2026-09-16 Turn the lid label to read portrait; verify label orientation from the mesh
    The lid text now reads upright with the RJ45 end at the top and the jacks on
    the left (LID_LABEL_ROT = 180, text along -X, top toward the RJ45 end). It read
    along the long axis before. Same size, depth and centre; the script now asserts
    the label block's clearance to the lid edge (9.8 mm), boss counterbores (11.6)
    and sight holes (22.0).
    verify_enclosure.py check 6 rasterises the engraving out of the exported lid and
    scores it against all eight rotations and mirrors: the old lid read rot 90, the
    re-export reads rot 180 (IoU 0.72). Re-exported on the Mac; every check passes.
    §6.4 added, item 27 now reprints case an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
    [aF4-trigger-case.step, aF4-trigger-lid.step, aF4-trigger-lid.stl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]
2026-09-17 Adapt the project to Claude Code on the Mac; add §9.2
    Sessions now run in Claude Code natively on the Mac rather than the Cowork
    sandbox, so most "session shell" limits no longer apply.
    - .claude/settings.json: commit/PR attribution off, firmware/secrets.yaml and
    archive/secrets unreadable, git push on the ask list, read-only allows, and
    hooks that regenerate the section index every turn and block a commit while
    it is stale
    - tools/section_index.py: the generator, moved out of docs/git-rules.md §6,
    with --check
    - §9.2 records the toolchain as checked 2026-09-17: KiCad 9.0.7 with pcbnew in
    its bundled Python, OCP 8.0.1 in ~/.venvs/cad (verify_enclosure.py passes),
    ESPHome 2026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
2026-09-18 §A4: J1 is rotated 180 deg on all five boards; 12 V moves to a panel jack
    The rev E boards arrived with the barrel jack facing inboard. gen_pcb.py places
    J1 at rot 270; CUI's STEP model puts the bore at footprint-local y +10.32, which
    at that rotation aims it at board x 133.68. J2 is correct at rot 90 -- the two
    connectors needed the same handedness. The pins sit at local x 0/-3.2/-8.5, so no
    rotation or bottom-side fit re-seats the part.
    A second error on the same jack: the enclosure's J1_Y was the body centre, not
    the bore axis, leaving the wall hole 1.25 mm off against 0.95 mm of slack. Three
    checks appeared to cover the jack and all three were hollow -- one tested a
    hand-typed coordina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
    [aF4-trigger-case.step, aF4-trigger-case.stl, aF4-trigger-hat-dummy.step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]
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2026-09-18 §A4: the 12 V pair is soldered; the lid is confirmed unchanged
    Wiring as executed on 2026-09-18: red to J1 pin 1 (+12V_RAW), black to pin 2
    (GNDP), pin 3 left bare, re-soldered once so the leads exit inboard.
    Same Sky's own PCB layout drawing corroborates the pad identification from a
    source independent of our footprint: it publishes 5.30 / 3.20 down the pin
    column and 6.20 / 3.60 down the shield-tab column, which is exactly what the
    board has. Pin 1 is in the tight pair with pin 3, the wide gap is the ground
    side in both columns, and the tab column reads the part's orientation using
    features that carry no wires -- useful when the pin row is buried in solder.
    Polarity stays UNVERIFIED unt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
2026-09-18 §11: the PoE board was swapped; item 16 closed and item 30 opened
    A duplicate Olimex ESP32-POE-ISO replaced the board that had been on the
    network since July. Flashed from the Mac, reservation moved in OPNsense,
    adopted in Home Assistant, OTA path proven.
    Recorded as §11, with three findings worth carrying:
    - Every board has two MACs three apart (Ethernet = base + 3). HA stores the
    base, DHCP reserves the Ethernet one. Both records were always right; the
    apparent contradiction in the docs was not one. Read the reservation MAC
    from the lease, never compute it.
    - HA raises a device-conflict repair on a MAC change. "Migrate configuration
    to new device" preserves the config entry, de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
2026-09-19 §12: commissioning 6.1-6.8 passed against the real feeder
    Every check in the gate run in one sitting on the assembled rev E hat.
    6.2 = 11.4 V, the value A2 predicted, and one the pre-09-01 band would
    have failed. 6.3 = 10.37 V with the LM1117 regulating rather than in
    dropout, so R4/R5 is confirmed by measurement. 6.4 = 0 V with D5 dark,
    the first hardware proof of the GPIO32 move. 6.5 held 10.37 V for 20 s
    with a clean falling edge, which answers bench item A6 incidentally.
    6.6 twice at 310.007 s and 310.013 s. 6.7 link solid, 6.8 the unit fed.
    12 V polarity settled first with a meter: black tail to TP4 a dead
    short, red to TP4 open.
    The reef system is plumbed and running - return pump 1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

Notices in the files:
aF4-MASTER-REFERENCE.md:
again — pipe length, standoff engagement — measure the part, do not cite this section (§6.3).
